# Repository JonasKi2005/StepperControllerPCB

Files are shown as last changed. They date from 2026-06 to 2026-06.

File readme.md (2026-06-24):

# 6-Axis Robot Arm — Firmware (v1: ESP32-S3 + TMC2209)

Firmware for a custom 3D-printed 6-axis robotic arm (~50 cm reach, 2 kg payload).
This is the **first-generation control board**, built around an **ESP32-S3** carrier
PCB driving **six TMC2209** stepper drivers, with a WiFi web UI for manual control
and bring-up.

> **Status:** This is the original ESP32-S3 board and is **retired**. It served as the
> first working bring-up of the arm, but the fabricated PCB had a UART addressing
> limitation (the driver address-select pins were not broken out as intended, so the
> address-multiplexing scheme below could not be used as designed). Development has
> since moved to a custom STM32G484 + TMC5240 board. This repo is kept as a reference
> for the working step-generation and driver code.

---

## Hardware

| Component | Part |
| --- | --- |
| MCU | ESP32-S3 (DevKitC-class carrier PCB) |
| Stepper drivers | 6× TMC2209 (BTT V1.2 modules, R_sense = 0.11 Ω) |
| Motors J1–J3 | NEMA 17 `17HS19-2004S1` (2 A) |
| Motors J4–J6 | NEMA 17 `17HS13-0404S` (0.4 A, short body) |
| Power | 24 V supply → drivers; logic rails on-board |

### Driver bus layout

The six drivers are split across **two UART buses**, three drivers per bus, using
the TMC2209's single-wire half-duplex UART with **address multiplexing** (each driver
on a bus is assigned address 0, 1, or 2):

```
UART1 ──┬── J1 (addr 0)      UART2 ──┬── J4 (addr 0)
        ├── J2 (addr 1)              ├── J5 (addr 1)
        └── J3 (addr 2)              └── J6 (addr 2)
```

All six drivers share a single **EN line**. The arm boots **disarmed** (EN held HIGH,
motors freewheeling) and only energizes after a POST to `/arm`.

---

## Firmware architecture

Built on **ESP-IDF (FreeRTOS)**. Four main translation units:

### `main.cpp` — entry point

Boot sequence: NVS init → construct one `TMC2209` per axis (UART + GPIO setup only) →
optionally push register config to each driver → start the motion controller →
bring up WiFi (the web server starts automatically once an IP is assigned). All pin
assignments and per-joint parameters (current, microsteps) live here in one place.

### `TMC2209.cpp` — driver class

Low-level UART register access with CRC, plus higher-level config:

- **`write_reg` / `read_reg`** — 8-byte datagrams, CRC-checked, with echo handling for
  single-wire half-duplex.
- **`init()`** — pushes GCONF/CHOPCONF/IHOLD_IRUN/PWMCONF and **verifies writes landed**
  by checking that `IFCNT` incremented by the expected count (your UART-wiring smoke test).
- **`set_current()`** — computes IRUN/IHOLD from a requested RMS current, automatically
  selecting `vsense` for best resolution.
- **`set_microsteps()`** — maps microstep count to the CHOPCONF MRES field.
- **`print_drv_status()`** — decodes DRV_STATUS flags (overtemp, short, open-load, etc.).

### `MotorController.cpp` — motion engine

The ESP32-S3 has only 4 hardware GPTimers, so **one timer per axis is impossible**.
Instead a **single shared timer fires at 20 kHz**, and the ISR uses **Bresenham-style
step accumulation** (the same pattern Marlin/Klipper use): each active axis accumulates
its `velocity_sps` per tick and emits a step pulse when the accumulator crosses the tick
rate. Supports per-axis jogging, absolute `move_to` targets, and clean stop/disarm.
Commands flow through a FreeRTOS queue to a dedicated motion task pinned to core 1.

### `Server.cpp` — WiFi + web UI

Connects as a WiFi station and serves a self-contained HTML control panel (no external
assets). The UI polls `/status` for live position and arm state, and exposes jog,
move-to, arming, current, and microstep controls.

#### HTTP API

| Method | Endpoint | Params | Purpose |
| --- | --- | --- | --- |
| GET | `/` | — | Web control UI |
| GET | `/status` | — | JSON: arm state, per-axis step counts, moving flags |
| POST | `/arm` | — | Energize drivers (EN low) |
| POST | `/disarm` | — | De-energize drivers (EN high) |
| POST | `/stop_all` | — | Stop all axes |
| POST | `/jog` | `axis`, `dir`, `v` | Continuous jog until stop |
| POST | `/stop` | `axis` | Stop one axis |
| POST | `/move_to` | `axis`, `target`, `v` | Move one axis to a step target |
| POST | `/current` | `axis`, `ma` | Set RMS current (50–2000 mA) |
| POST | `/microsteps` | `axis`, `us` | Set microstepping (1…256) |

---

## Building & flashing

Requires the **ESP-IDF** toolchain. From the firmware directory:

```bash
idf.py set-target esp32s3
idf.py build
idf.py -p <PORT> flash monitor
```

On macOS the ESP32-S3 enumerates via the **Silicon Labs CP210x** driver; `<PORT>` is
typically `/dev/cu.SLAB_USBtoUART` or similar.

Set your WiFi credentials (`WIFI_SSID` / `WIFI_PASS`) before building. On boot the
serial monitor prints the assigned IP address — open it in a browser to reach the UI.

> **Bring-up note:** Driver `init()` is commented out in `main.cpp` by default so the
> board can boot and run the web UI without working UART to the drivers. Re-enable it
> once the UART wiring is verified — `init()` will report via `IFCNT` whether register
> writes are actually reaching each driver.

---

## Known limitations of this board

- **UART addressing:** the address-multiplexing scheme above depends on each driver's
  address-select pins being individually set. On the fabricated board this wasn't the
  case and has to be fixed in the kicad files.
- No closed-loop feedback — purely open-loop step counting.
- This is my first PCB so there probably will be some other errors, since the PCB wasn't tested so far.

---

## A note on the code

**The code in this repository is handwritten.** AI was used only to polish and comment
it — the architecture, logic, and implementation decisions are my own.

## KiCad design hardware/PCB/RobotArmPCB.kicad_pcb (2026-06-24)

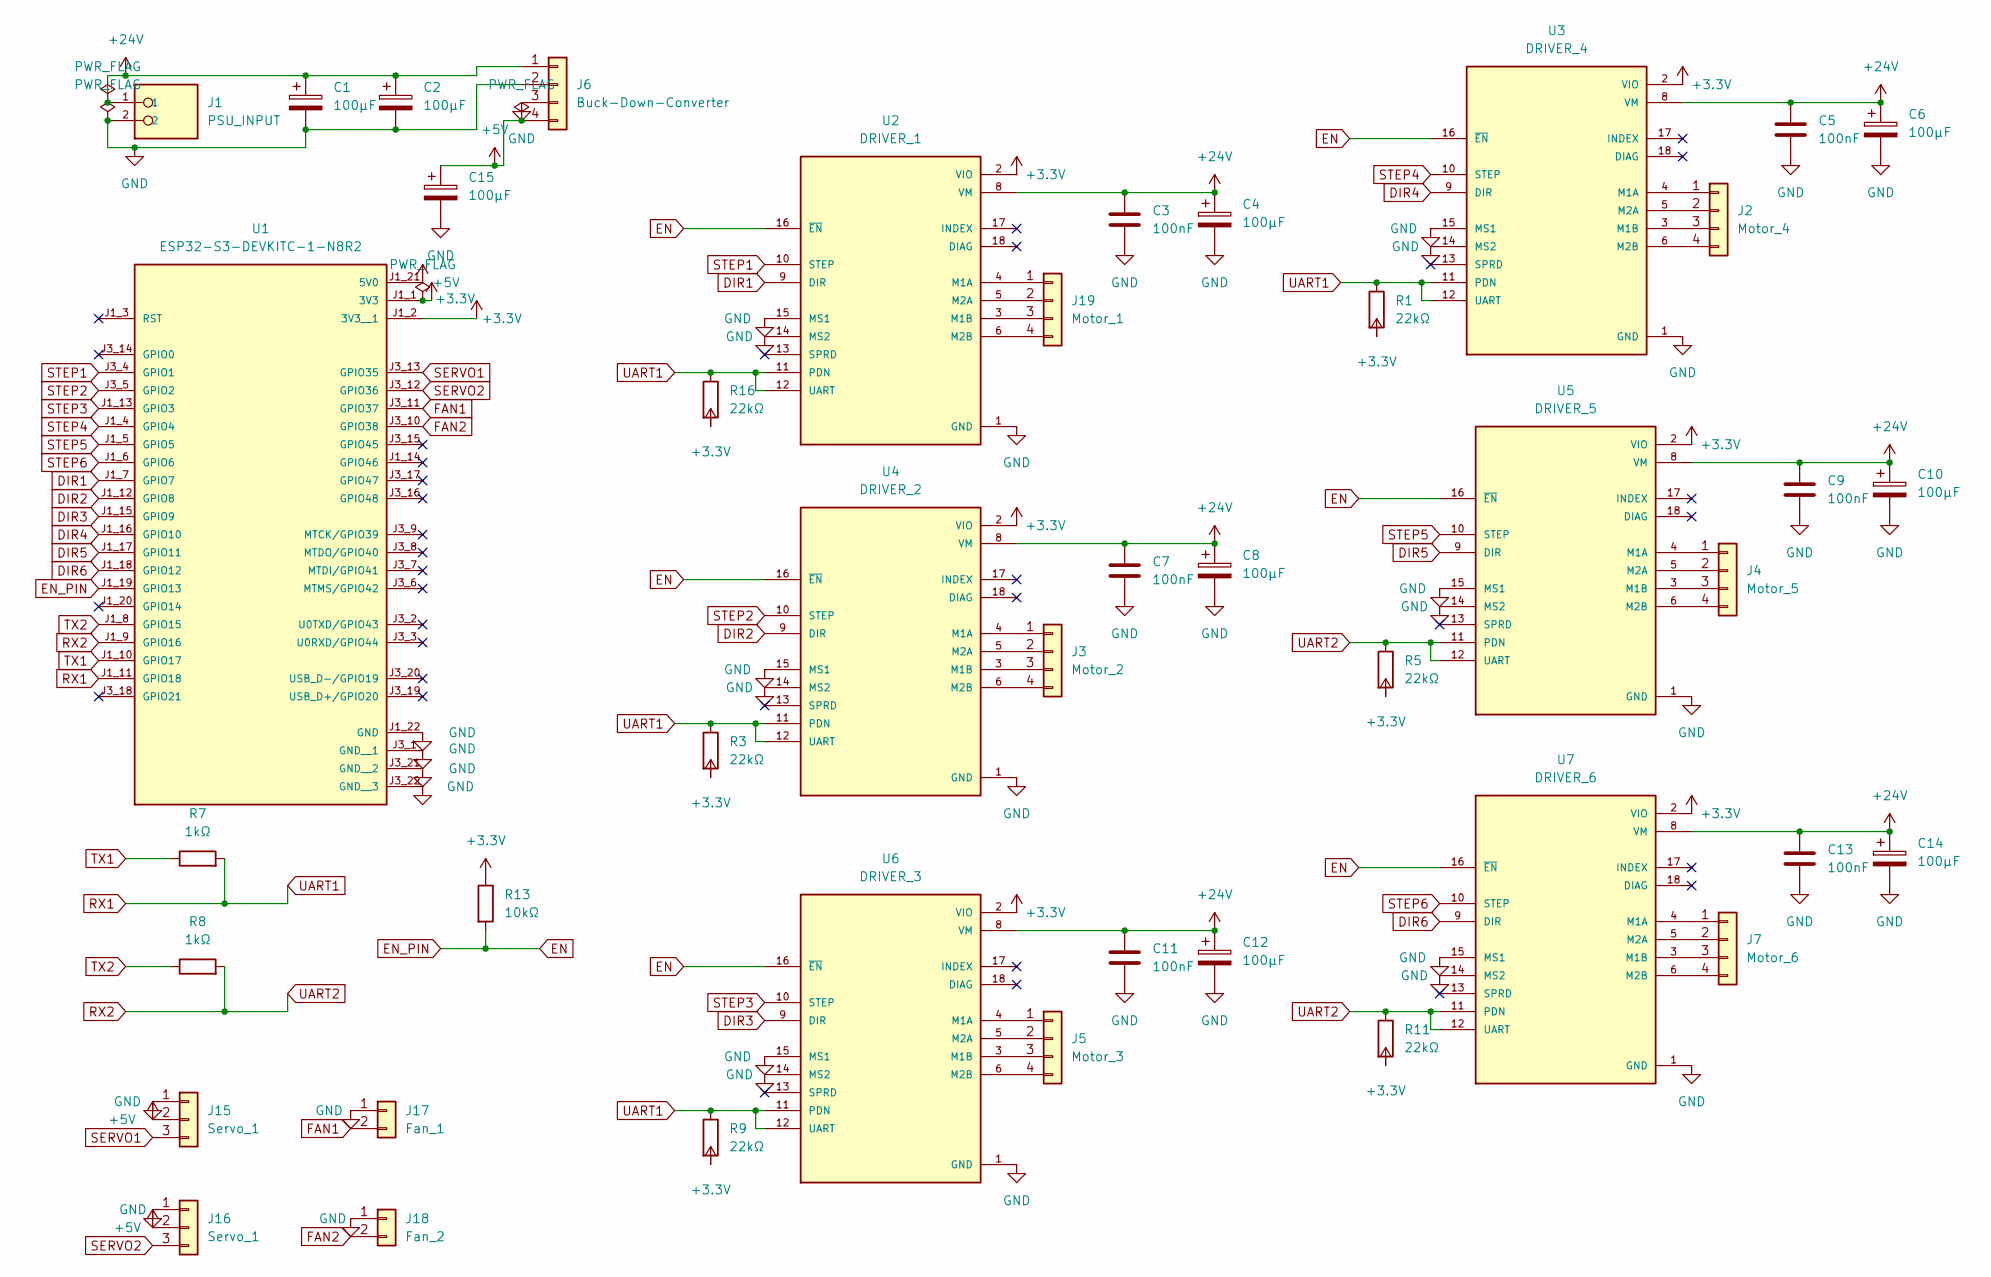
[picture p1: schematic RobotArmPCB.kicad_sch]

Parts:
C1, C2, C4, C6, C8, C10, C12, C14, C15: 100µF; CP_Radial_D6.3mm_P2.50mm
C3, C5, C7, C9, C11, C13: 100nF; C_Disc_D5.0mm_W2.5mm_P2.50mm
J1: PSU_INPUT; PHOENIX_1935161; PARTREV 14.12.2022
J2: Motor_4; JST_XH_B4B-XH-A_1x04_P2.50mm_Vertical
J3: Motor_2; JST_XH_B4B-XH-A_1x04_P2.50mm_Vertical
J4: Motor_5; JST_XH_B4B-XH-A_1x04_P2.50mm_Vertical
J5: Motor_3; JST_XH_B4B-XH-A_1x04_P2.50mm_Vertical
J6: Buck-Down-Converter; YAAJ_DCDC_StepDown_LM2596
J7: Motor_6; JST_XH_B4B-XH-A_1x04_P2.50mm_Vertical
J15, J16: Servo_1; PinHeader_1x03_P2.54mm_Vertical
J17: Fan_1; PinHeader_1x02_P2.54mm_Vertical
J18: Fan_2; PinHeader_1x02_P2.54mm_Vertical
J19: Motor_1; JST_XH_B4B-XH-A_1x04_P2.50mm_Vertical
R1, R3, R5, R9, R11, R16: 22kΩ; R_Axial_DIN0207_L6.3mm_D2.5mm_P7.62mm_Horizontal
R7, R8: 1kΩ; R_Axial_DIN0207_L6.3mm_D2.5mm_P7.62mm_Horizontal
R13: 10kΩ; R_Axial_DIN0207_L6.3mm_D2.5mm_P7.62mm_Horizontal
U1: ESP32-S3-DEVKITC-1-N8R2; XCVR_ESP32-S3-DEVKITC-1-N8R2; PARTREV V1
U2: DRIVER_1; MODULE_TMC2209_SILENTSTEPSTICK; PARTREV 1.20
U3: DRIVER_4; MODULE_TMC2209_SILENTSTEPSTICK; PARTREV 1.20
U4: DRIVER_2; MODULE_TMC2209_SILENTSTEPSTICK; PARTREV 1.20
U5: DRIVER_5; MODULE_TMC2209_SILENTSTEPSTICK; PARTREV 1.20
U6: DRIVER_3; MODULE_TMC2209_SILENTSTEPSTICK; PARTREV 1.20
U7: DRIVER_6; MODULE_TMC2209_SILENTSTEPSTICK; PARTREV 1.20

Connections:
+3.3V: R1.2, R3.2, R5.2, R9.2, R11.2, R13.1, R16.2, U1.J1_1 (3V3), U1.J1_2 (3V3__1), U2.2 (VIO), U3.2 (VIO), U4.2 (VIO), U5.2 (VIO), U6.2 (VIO), U7.2 (VIO)
+5V: C15.1, J6.4, J15.2, J16.2, U1.J1_21 (5V0)
+24V: C1.1, C2.1, C3.1, C4.1, C5.1, C6.1, C7.1, C8.1, C9.1, C10.1, C11.1, C12.1, C13.1, C14.1, J1.1, J6.1, U2.8 (VM), U3.8 (VM), U4.8 (VM), U5.8 (VM), U6.8 (VM), U7.8 (VM)
DIR1: U1.J1_7 (GPIO7), U2.9 (DIR)
DIR2: U1.J1_12 (GPIO8), U4.9 (DIR)
DIR3: U1.J1_15 (GPIO9), U6.9 (DIR)
DIR4: U1.J1_16 (GPIO10), U3.9 (DIR)
DIR5: U1.J1_17 (GPIO11), U5.9 (DIR)
DIR6: U1.J1_18 (GPIO12), U7.9 (DIR)
EN: R13.2, U1.J1_19 (GPIO13), U2.16 (~EN), U3.16 (~EN), U4.16 (~EN), U5.16 (~EN), U6.16 (~EN), U7.16 (~EN)
FAN1: J17.2, U1.J3_11 (GPIO37)
FAN2: J18.2, U1.J3_10 (GPIO38)
GND: C1.2, C2.2, C3.2, C4.2, C5.2, C6.2, C7.2, C8.2, C9.2, C10.2, C11.2, C12.2, C13.2, C14.2, C15.2, J1.2, J6.2, J6.3, J15.1, J16.1, J17.1, J18.1, U1.J1_22 (GND), U1.J3_1 (GND__1), U1.J3_21 (GND__2), U1.J3_22 (GND__3), U2.1 (GND), U2.7 (GND), U2.14 (MS2), U2.15 (MS1), U3.1 (GND), U3.7 (GND), U3.14 (MS2), U3.15 (MS1), U4.1 (GND), U4.7 (GND), U4.14 (MS2), U4.15 (MS1), U5.1 (GND), U5.7 (GND), U5.14 (MS2), U5.15 (MS1), U6.1 (GND), U6.7 (GND), U6.14 (MS2), U6.15 (MS1), U7.1 (GND), U7.7 (GND), U7.14 (MS2), U7.15 (MS1)
unnamed: J2.1, U3.4 (M1A)
unnamed: J2.2, U3.5 (M2A)
unnamed: J2.3, U3.3 (M1B)
unnamed: J2.4, U3.6 (M2B)
unnamed: J3.1, U4.4 (M1A)
unnamed: J3.2, U4.5 (M2A)
unnamed: J3.3, U4.3 (M1B)
unnamed: J3.4, U4.6 (M2B)
unnamed: J4.1, U5.4 (M1A)
unnamed: J4.2, U5.5 (M2A)
unnamed: J4.3, U5.3 (M1B)
unnamed: J4.4, U5.6 (M2B)
unnamed: J5.1, U6.4 (M1A)
unnamed: J5.2, U6.5 (M2A)
unnamed: J5.3, U6.3 (M1B)
unnamed: J5.4, U6.6 (M2B)
unnamed: J7.1, U7.4 (M1A)
unnamed: J7.2, U7.5 (M2A)
unnamed: J7.3, U7.3 (M1B)
unnamed: J7.4, U7.6 (M2B)
unnamed: J19.1, U2.4 (M1A)
unnamed: J19.2, U2.5 (M2A)
unnamed: J19.3, U2.3 (M1B)
unnamed: J19.4, U2.6 (M2B)
RX1: R1.1, R3.1, R7.2, R9.1, R16.1, U1.J1_11 (GPIO18), U2.11 (PDN), U2.12 (UART), U3.11 (PDN), U3.12 (UART), U4.11 (PDN), U4.12 (UART), U6.11 (PDN), U6.12 (UART)
RX2: R5.1, R8.2, R11.1, U1.J1_9 (GPIO16), U5.11 (PDN), U5.12 (UART), U7.11 (PDN), U7.12 (UART)
SERVO1: J15.3, U1.J3_13 (GPIO35)
SERVO2: J16.3, U1.J3_12 (GPIO36)
STEP1: U1.J3_4 (GPIO1), U2.10 (STEP)
STEP2: U1.J3_5 (GPIO2), U4.10 (STEP)
STEP3: U1.J1_13 (GPIO3), U6.10 (STEP)
STEP4: U1.J1_4 (GPIO4), U3.10 (STEP)
STEP5: U1.J1_5 (GPIO5), U5.10 (STEP)
STEP6: U1.J1_6 (GPIO6), U7.10 (STEP)
TX1: R7.1, U1.J1_10 (GPIO17)
TX2: R8.1, U1.J1_8 (GPIO15)

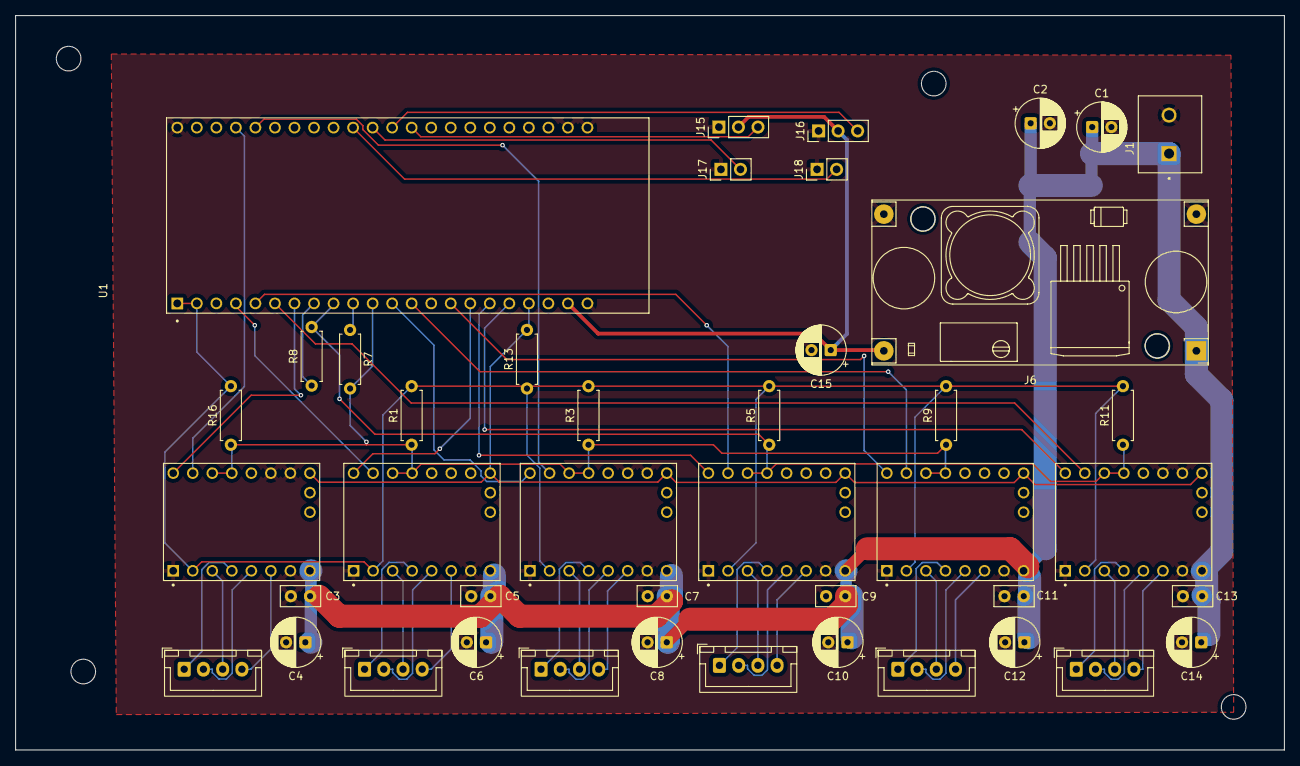
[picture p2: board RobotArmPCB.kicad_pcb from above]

Board: 2 copper layers, 165.0 x 95.5 mm, 43 parts (0 on the bottom side), 49 nets.

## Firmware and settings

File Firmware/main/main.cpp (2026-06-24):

// =============================================================================
//  6-axis Robot Arm Controller — application entry point
// =============================================================================
//
//  Boot order:
//    1. NVS flash init (required by WiFi)
//    2. Construct one TMC2209 per axis. The constructor configures the UART
//       peripheral and step/dir/en GPIOs but does NOT talk to the driver yet.
//    3. Call init() on each driver to push the register config over UART.
//    4. Hand the drivers to the motion controller, which spawns the motion
//       task and configures the per-axis GPTimers.
//    5. Bring up WiFi. The IP-got handler starts the webserver once an IP
//       address is assigned.
//
//  Important: the arm boots DISARMED. EN is held HIGH so all motors freewheel
//  until you POST to /arm.
// =============================================================================

#include "freertos/FreeRTOS.h"
#include "freertos/task.h"
#include "esp_log.h"
#include "nvs_flash.h"

#include "TMC2209.hpp"
#include "MotorController.hpp"
#include "Server.hpp"

static const char *TAG = "main";

// =============================================================================
//  Pin configuration — taken from the KiCad schematic for the ESP32-S3-DEVKITC
//  carrier PCB. If you ever change wiring, update HERE and only here.
//
//  Pins to avoid on ESP32-S3:
//    GPIO 0       — boot strapping
//    GPIO 19, 20  — USB D-/D+
//    GPIO 26..32  — connected to onboard flash/PSRAM
//    GPIO 33, 34  — don't exist
//    GPIO 45, 46  — strapping pins (boot behaviour)
// =============================================================================

// ---- Shared EN line ----
//
// All six TMC2209 modules tie EN together. The motion controller pulls this
// LOW to arm the arm, HIGH to disarm.
constexpr gpio_num_t PIN_ARM_EN = GPIO_NUM_13;

// ---- UART bus 1 — drivers J1, J2, J3 (addresses 0, 1, 2) ----
constexpr uart_port_t UART_BUS_1 = UART_NUM_1;
constexpr gpio_num_t PIN_UART1_TX = GPIO_NUM_17; // TX1 on schematic
constexpr gpio_num_t PIN_UART1_RX = GPIO_NUM_18; // RX1 on schematic

// ---- UART bus 2 — drivers J4, J5, J6 (addresses 0, 1, 2) ----
constexpr uart_port_t UART_BUS_2 = UART_NUM_2;
constexpr gpio_num_t PIN_UART2_TX = GPIO_NUM_15; // TX2 on schematic
constexpr gpio_num_t PIN_UART2_RX = GPIO_NUM_16; // RX2 on schematic

// ---- STEP / DIR pins, one pair per axis ----
constexpr gpio_num_t PIN_STEP_J1 = GPIO_NUM_1;
constexpr gpio_num_t PIN_DIR_J1 = GPIO_NUM_7;

constexpr gpio_num_t PIN_STEP_J2 = GPIO_NUM_2;
constexpr gpio_num_t PIN_DIR_J2 = GPIO_NUM_8;

constexpr gpio_num_t PIN_STEP_J3 = GPIO_NUM_3;
constexpr gpio_num_t PIN_DIR_J3 = GPIO_NUM_9;

constexpr gpio_num_t PIN_STEP_J4 = GPIO_NUM_4;
constexpr gpio_num_t PIN_DIR_J4 = GPIO_NUM_10;

constexpr gpio_num_t PIN_STEP_J5 = GPIO_NUM_5;
constexpr gpio_num_t PIN_DIR_J5 = GPIO_NUM_11;

constexpr gpio_num_t PIN_STEP_J6 = GPIO_NUM_6;
constexpr gpio_num_t PIN_DIR_J6 = GPIO_NUM_12;

// =============================================================================
//  Per-joint driver parameters
// =============================================================================
//
//  Currents follow the BOM:
//    J1 (base)     17HS19-2004S1, 2A rated -> 1400 mA RMS
//    J2 (shoulder) 17HS19-2004S1, 2A rated -> 1800 mA RMS  (highest load)
//    J3 (elbow)    17HS19-2004S1, 2A rated -> 1600 mA RMS
//    J4..J6 wrist  17HS13-0404S,  0.4A     ->  320 mA RMS
//
//  Microsteps: 16 everywhere to start. With CHOPCONF.intpol=1 the driver
//  internally interpolates to 256 so motion is smooth without overloading
//  the ESP32 with step rates.

struct JointConfig
{
    uart_port_t uart;
    gpio_num_t uart_tx;
    gpio_num_t uart_rx;
    gpio_num_t step;
    gpio_num_t dir;
    uint8_t uart_addr;
    uint16_t current_ma;
    uint16_t microsteps;
};

static const JointConfig joint_cfg[NUM_AXES] = {
    // J1 base
    {UART_BUS_1, PIN_UART1_TX, PIN_UART1_RX, PIN_STEP_J1, PIN_DIR_J1, 0, 1400, 16},
    // J2 shoulder
    {UART_BUS_1, PIN_UART1_TX, PIN_UART1_RX, PIN_STEP_J2, PIN_DIR_J2, 1, 1800, 16},
    // J3 elbow
    {UART_BUS_1, PIN_UART1_TX, PIN_UART1_RX, PIN_STEP_J3, PIN_DIR_J3, 2, 1600, 16},
    // J4 wrist rotation
    {UART_BUS_2, PIN_UART2_TX, PIN_UART2_RX, PIN_STEP_J4, PIN_DIR_J4, 0, 320, 16},
    // J5 wrist pitch
    {UART_BUS_2, PIN_UART2_TX, PIN_UART2_RX, PIN_STEP_J5, PIN_DIR_J5, 1, 320, 16},
    // J6 wrist roll
    {UART_BUS_2, PIN_UART2_TX, PIN_UART2_RX, PIN_STEP_J6, PIN_DIR_J6, 2, 320, 16},
};

// Drivers live in static storage so their addresses are stable for the
// lifetime of the program.
static TMC2209 *joints[NUM_AXES] = {};

// =============================================================================
//  Entry point
// =============================================================================

extern "C" void app_main()
{
    ESP_LOGI(TAG, "=== Robot Arm boot ===");

    // ---- 1. NVS flash (WiFi needs this) ----
    esp_err_t err = nvs_flash_init();
    if (err == ESP_ERR_NVS_NO_FREE_PAGES || err == ESP_ERR_NVS_NEW_VERSION_FOUND)
    {
        ESP_ERROR_CHECK(nvs_flash_erase());
        ESP_ERROR_CHECK(nvs_flash_init());
    }

    // ---- 2. Construct drivers ----
    //
    // We allocate on the heap so the objects survive after app_main returns.
    // The constructor sets up UART + GPIO but does no TMC register writes yet.
    for (int i = 0; i < NUM_AXES; i++)
    {
        const JointConfig &c = joint_cfg[i];
        joints[i] = new TMC2209(
            c.uart, c.uart_tx, c.uart_rx,
            c.step, c.dir, PIN_ARM_EN,
            c.uart_addr,
            /* single_wire */ true);
        ESP_LOGI(TAG, "J%d driver constructed (UART%d addr %u step=%d dir=%d)",
                 i + 1, (int)c.uart, c.uart_addr, (int)c.step, (int)c.dir);
    }

    // ---- 3. Push register config to each driver over UART ----
    //
    // init() verifies that IFCNT incremented correctly — if the UART wiring
    // is broken, this is where you find out.
    // for (int i = 0; i < NUM_AXES; i++)
    // {
    //     const JointConfig &c = joint_cfg[i];
    //     if (!joints[i]->init(c.current_ma, c.microsteps))
    //     {
    //         ESP_LOGE(TAG, "J%d driver init FAILED — check UART wiring", i + 1);
    //     }
    // }

    // ---- 4. Motion controller ----
    //
    // Caches step pins, configures GPTimers, creates motion queue, spawns
    // motion task on core 1. Arm stays disarmed (EN HIGH).
    init_motor_controller(joints);

    // ---- 5. WiFi + webserver ----
    //
    // connect_wifi blocks until either connected or MAX_FAILURES reached.
    // start_webserver is invoked from the IP-got event handler once an IP is
    // assigned, so by the time connect_wifi returns SUCESS, the HTTP API is
    // already live.
    if (connect_wifi() != WIFI_SUCESS)
    {
        ESP_LOGE(TAG, "WiFi connection failed — server not started");
        // We don't return; the motion task is still running and the arm
        // can in principle be driven from a serial console if you add one.
    }
    else
    {
        ESP_LOGI(TAG, "=== Boot complete, web UI available ===");
    }

    // app_main can return — FreeRTOS keeps the motion task and HTTP server
    // running. The idle task handles whatever cleanup is needed.
}

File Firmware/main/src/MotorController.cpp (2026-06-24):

#include "MotorController.hpp"

#include <string.h>
#include "esp_log.h"
#include "esp_rom_sys.h"

static const char *TAG = "motion";

// ---------------------------------------------------------------------------
// Shared step generator
// ---------------------------------------------------------------------------
//
// ESP32-S3 has only 4 hardware GPTimers, so we cannot use one timer per
// axis. Instead, a SINGLE timer fires at TICK_HZ and the ISR decides on
// each tick which axes need a step pulse.
//
// Each axis accumulates `velocity_sps` into `step_accumulator` every tick.
// When the accumulator >= TICK_HZ, we emit one step and subtract TICK_HZ.
// This is the standard "Bresenham stepping" pattern used by Marlin/Klipper.
//
// TICK_HZ must be >= max desired step rate per axis. 20 kHz gives:
//   - 50 µs between ticks, plenty of headroom in the ISR
//   - Max output 20,000 steps/sec/axis — way above any realistic robot arm move
//
constexpr uint32_t TICK_HZ = 20000;                    // 20 kHz step generator
constexpr uint64_t TICK_PERIOD_US = 1000000 / TICK_HZ; // = 50 µs

// ---------------------------------------------------------------------------
// Globals
// ---------------------------------------------------------------------------

AxisState axes[NUM_AXES] = {};
gpio_num_t step_pins[NUM_AXES] = {};
gptimer_handle_t step_timers[NUM_AXES] = {}; // unused; kept for header ABI
TMC2209 *drivers[NUM_AXES] = {};

QueueHandle_t motion_queue = nullptr;
TaskHandle_t motion_task_handle = nullptr;

// Step generator state — accumulator-based fractional step rate
static volatile int32_t step_accumulator[NUM_AXES] = {};

// The single shared timer
static gptimer_handle_t step_tick_timer = nullptr;
static volatile uint8_t active_axis_mask = 0; // bit i set if axis i is running

// ---------------------------------------------------------------------------
// Forward declarations — IRAM_ATTR on both decl and def
// ---------------------------------------------------------------------------

static void motion_task(void *arg);
static void handle_command(const MotionCmd &cmd);
static void start_axis(int axis);
static void stop_axis(int axis);
static void init_step_generator();

// ===========================================================================
// Public API
// ===========================================================================

void init_motor_controller(TMC2209 *driver_instances[NUM_AXES])
{
    for (int i = 0; i < NUM_AXES; i++)
    {
        drivers[i] = driver_instances[i];
        step_pins[i] = drivers[i]->step_pin();
        axes[i] = {};
        step_accumulator[i] = 0;
    }

    // Shared EN pin — held HIGH (disarmed) at boot
    gpio_config_t io = {};
    io.pin_bit_mask = (1ULL << ARM_ENABLE_PIN);
    io.mode = GPIO_MODE_OUTPUT;
    io.pull_up_en = GPIO_PULLUP_DISABLE;
    io.pull_down_en = GPIO_PULLDOWN_DISABLE;
    io.intr_type = GPIO_INTR_DISABLE;
    gpio_config(&io);
    gpio_set_level(ARM_ENABLE_PIN, 1);

    // ONE shared step generator timer (not 6)
    init_step_generator();

    motion_queue = xQueueCreate(32, sizeof(MotionCmd));
    configASSERT(motion_queue != nullptr);

    BaseType_t ok = xTaskCreatePinnedToCore(
        motion_task, "motion", 4096, nullptr,
        configMAX_PRIORITIES - 2,
        &motion_task_handle,
        1);
    configASSERT(ok == pdPASS);

    ESP_LOGI(TAG, "motor controller ready, %d axes, %u Hz tick, disarmed",
             NUM_AXES, (unsigned)TICK_HZ);
}

bool enqueue_command(const MotionCmd &cmd)
{
    if (motion_queue == nullptr)
        return false;
    return xQueueSend(motion_queue, &cmd, pdMS_TO_TICKS(10)) == pdTRUE;
}

// ===========================================================================
// Motion task
// ===========================================================================

static void motion_task(void *)
{
    MotionCmd cmd;
    while (true)
    {
        if (xQueueReceive(motion_queue, &cmd, portMAX_DELAY) == pdTRUE)
        {
            handle_command(cmd);
        }
    }
}

// ---------------------------------------------------------------------------
// Shared ISR — runs at TICK_HZ. Iterates active axes and emits steps.
// ---------------------------------------------------------------------------
static bool IRAM_ATTR step_tick_isr(gptimer_handle_t /*timer*/,
                                    const gptimer_alarm_event_data_t * /*edata*/,
                                    void * /*user_data*/)
{
    uint8_t mask = active_axis_mask;
    if (mask == 0)
        return false; // no work

    BaseType_t woken = pdFALSE;

    for (int axis = 0; axis < NUM_AXES; axis++)
    {
        if ((mask & (1u << axis)) == 0)
            continue;

        AxisState &a = axes[axis];

        // Asked to stop?
        if (!a.moving)
        {
            active_axis_mask &= ~(1u << axis);
            continue;
        }

        // MOVE_TO target reached?
        if (!a.jog_mode)
        {
            int32_t remaining = a.target_steps - a.current_steps;
            bool done = (a.direction > 0 && remaining <= 0) ||
                        (a.direction < 0 && remaining >= 0);
            if (done)
            {
                a.moving = false;
                active_axis_mask &= ~(1u << axis);

                MotionCmd done_cmd = {};
                done_cmd.type = CmdType::MOVE_DONE;
                done_cmd.axis = (uint8_t)axis;
                xQueueSendFromISR(motion_queue, &done_cmd, &woken);
                continue;
            }
        }

        // Bresenham step accumulator
        step_accumulator[axis] += (int32_t)a.velocity_sps;
        if (step_accumulator[axis] >= (int32_t)TICK_HZ)
        {
            step_accumulator[axis] -= (int32_t)TICK_HZ;

            gpio_set_level(step_pins[axis], 1);
            esp_rom_delay_us(1);
            gpio_set_level(step_pins[axis], 0);

            a.current_steps += a.direction;
        }
    }

    return woken == pdTRUE;
}

// ===========================================================================
// Command handler
// ===========================================================================
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
